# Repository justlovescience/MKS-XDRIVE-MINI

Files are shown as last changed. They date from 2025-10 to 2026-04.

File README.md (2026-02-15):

# MKS XDRIVE Mini FOC Driver: Full Setup Guide & Firmware

main

A comprehensive guide for the **MKS XDRIVE Mini**, a cost-effective, high-performance FOC driver for robotics. This repository contains configuration files, unbricking procedures, and multi-driver CAN bus setup instructions.

---

## 📺 Video Tutorial
Watch the step-by-step video guide here:
[**MKS XDRIVE Mini Full Instruction & Setup**](https://youtu.be/yRx7dsJmNvU?si=e_iXddEL_CQ9xSlw)

---

## 🚀 Quick Start (Windows)
Follow these steps to configure your driver using the ODrive tool:

1. **Install Python:** Download from python.org. 
   * **Important:** Select "Add python.exe to PATH" during installation.
2. **Install ODrive Tool:** Open PowerShell and install the ODrive package version 0.5.1.post0.
3. **Configuration:** Run **odrivetool** in your terminal. Use the commands provided in the **my_config.txt** file.
4. **Motor Tuning:** Ensure you set your pole pairs correctly. For example, for an LA8308 170kV motor, you would enter:
   **odrv0.axis0.motor.config.pole_pairs = 20**
   *Note: Calculate this by counting your motor magnets and dividing by 2.*

---

## 🛠 Hardware & Compatibility
* **Web GUI Interface:** For a visual setup, use this [Awesome WEB GUI](https://github.com/MoonLighTingPY/odrive3.6_web_gui).
* **Arduino/ESP32 Setup:** Ensure your board has CAN support.
    * For **ESP32**, place the **ODriveEsp32Twai.hpp** adapter in your arduino/libraries/OdriveArduino/src folder.
* **macOS Support:** odrivetool is functional on Mac, but the GUI is currently unsupported.

---

## ⚠️ Critical Notes & Troubleshooting

### 1. Avoid Bricking the Driver
* **Do NOT** use the "upgrade" command in odrivetool. This driver ships with modified **v0.5.1 firmware**; standard upgrades will brick the device.
* **Unbricking:** If bricked, you must use an **ST-Link programmer**. You can find dumped original firmware in this repository, you will need ST-linkV2 to unbrick.

### 2. CAN Bus Conflicts (Multi-Driver Setup)
By default, the MKS XDRIVE Mini acts like a dual-axis ODrive. This causes CAN ID conflicts when connecting multiple drivers.
* **The Fix:** Change the "ghost" Axis1 to a "listen-only" ID to clear the bus by setting:
  **odrv0.axis1.config.can_node_id = 63**

### 3. Firmware Versions
Current testing shows that updating to **v0.5.6** may result in motor inactivity (likely due to different pin assignments for the DRV8301). Stick to v0.5.1 for now. 

---

## 🔌 Wiring & Schematics
### ESP32-S3 Connection Diagram
esp32_s3_two_drivers_schematic

---
*Disclaimer: This repository is a community-made guide. I have no affiliation with the manufacturer.*

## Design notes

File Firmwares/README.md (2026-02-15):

here will be some firmwares for this driver, work in progress
MKS_XDRIVE_MINI_original_FW.bin is original firmware dumped from driver, in case you bricked yoor board with DFU update. You will need stlink to flash it.

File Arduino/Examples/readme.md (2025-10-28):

Couple examples of code to run drivers through CAN

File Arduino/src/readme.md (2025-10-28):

Put ODriveEsp32Twai.hpp in Odrive library folder

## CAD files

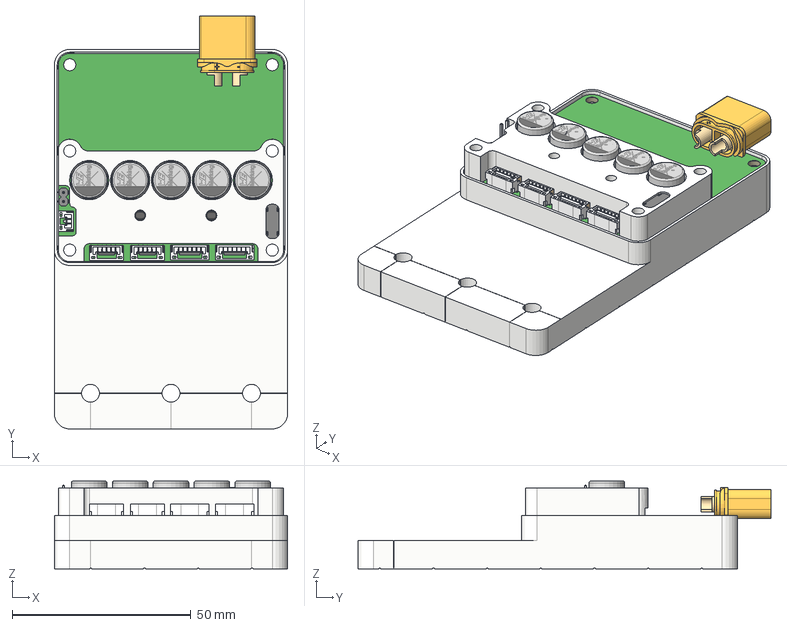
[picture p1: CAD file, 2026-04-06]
3Dmodels/LA8308 motor mount and driver assembly.step
65.2 x 115.4 x 24.6 mm

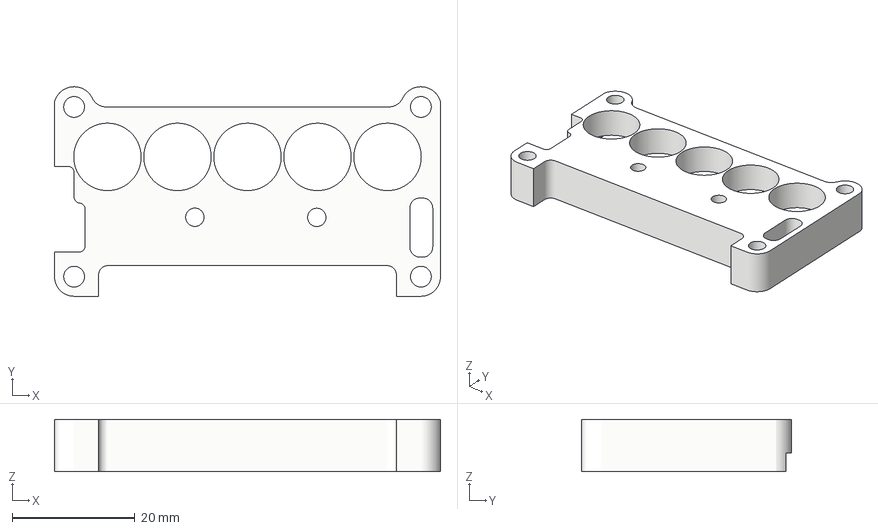
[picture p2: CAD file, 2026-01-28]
3Dmodels/half_bracket_for_3dprinting.3mf
63.0 x 34.2 x 8.50 mm

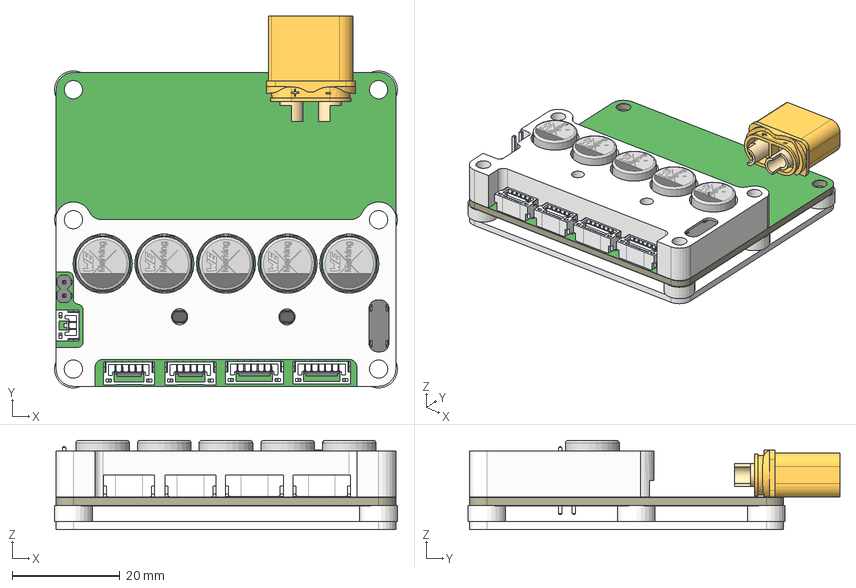
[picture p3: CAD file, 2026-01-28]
3Dmodels/mks xdrive mini xt60.step
63.6 x 68.9 x 16.6 mm

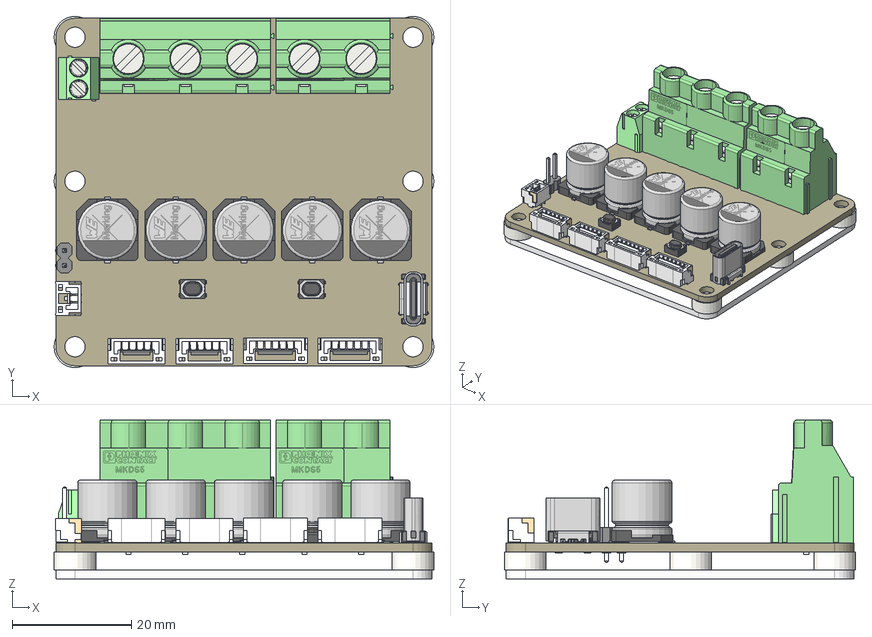
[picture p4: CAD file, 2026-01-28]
3Dmodels/mks xdrive mini.step
63.6 x 58.7 x 26.6 mm

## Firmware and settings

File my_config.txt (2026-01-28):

odrv0.erase_configuration() 						

odrv0.config.brake_resistance = 2.0
odrv0.config.dc_bus_undervoltage_trip_level = 8.0
odrv0.config.dc_bus_overvoltage_trip_level = 56.0
odrv0.config.dc_max_positive_current = 20.0
odrv0.config.dc_max_negative_current = -3.0
odrv0.config.max_regen_current = 0
odrv0.save_configuration()

odrv0.axis0.motor.config.pole_pairs = 20
odrv0.axis0.motor.config.calibration_current = 5
odrv0.axis0.motor.config.resistance_calib_max_voltage = 2
odrv0.axis0.motor.config.motor_type = MOTOR_TYPE_HIGH_CURRENT
odrv0.axis0.motor.config.current_lim = 15
odrv0.axis0.motor.config.requested_current_range = 20
odrv0.save_configuration()

odrv0.axis0.encoder.config.mode = ENCODER_MODE_SPI_ABS_AMS
odrv0.axis0.encoder.config.abs_spi_cs_gpio_pin = 7
odrv0.axis0.encoder.config.cpr = 16384
odrv0.axis0.encoder.config.bandwidth = 3000
odrv0.axis0.encoder.config.calib_range = 10
odrv0.save_configuration()

odrv0.axis0.controller.config.control_mode = CONTROL_MODE_POSITION_CONTROL
odrv0.axis0.controller.config.vel_limit = 120
odrv0.axis0.controller.config.pos_gain = 30
odrv0.axis0.controller.config.vel_gain = 0.02  				
odrv0.axis0.controller.config.vel_integrator_gain = 0.2
odrv0.axis0.controller.config.input_mode = INPUT_MODE_TRAP_TRAJ
odrv0.axis0.trap_traj.config.vel_limit = 30
odrv0.axis0.trap_traj.config.accel_limit = 5  
odrv0.axis0.trap_traj.config.decel_limit = 5
odrv0.save_configuration()
odrv0.reboot()

odrv0.axis0.requested_state = AXIS_STATE_MOTOR_CALIBRATION  		
odrv0.axis0.motor.config.pre_calibrated = True				
odrv0.axis0.requested_state = AXIS_STATE_ENCODER_OFFSET_CALIBRATION 	
odrv0.axis0.config.startup_encoder_offset_calibration = True   			
odrv0.axis0.requested_state = AXIS_STATE_CLOSED_LOOP_CONTROL		
odrv0.axis0.config.startup_closed_loop_control = True			
odrv0.save_configuration()
odrv0.reboot()  

odrv0.axis0.controller.input_pos = 50
odrv0.axis0.controller.input_pos = 0
odrv0.axis0.requested_state = AXIS_STATE_IDLE

odrv0.axis0.config.can_node_id = 0 
odrv0.can.set_baud_rate(500000)
odrv0.axis1.config.can_node_id = 63
  

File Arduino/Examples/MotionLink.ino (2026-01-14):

/*
 *  One way motion  control test
 * 
 * Test setup:
 * - Motor 0: Torque control mode with zero torque (move by hand)
 * - Motor 1: Position control mode following Motor 0's position
 * 
 * This tests the transition from torque control to position control.
 * 
 * Hardware:
 * - ESP32 + CAN transceiver
 * - Two ODrive motors (Node 0 and 1)
 */

#include <Arduino.h>
#include <ESP32-TWAI-CAN.hpp>
#include "ODriveCAN.h"
#include "ODriveEsp32Twai.hpp"

// Configuration
#define CAN_BAUDRATE   500000
#define TX_GPIO_NUM    5
#define RX_GPIO_NUM    4
#define ODRV0_NODE_ID  0
#define ODRV1_NODE_ID  1

// Position control parameters
#define POS_GAIN       20.0f   // Position gain for slave motor
#define VEL_GAIN       0.1f    // Velocity gain for slave motor
#define VEL_INT_GAIN   0.0f    // Velocity integrator gain
#define VEL_LIMIT      10.0f   // Velocity limit (rev/s)
#define CURRENT_LIMIT  10.0f   // Current limit (A)

// Update frequency parameters
#define UPDATE_FREQ_HZ  100    // Update frequency in Hz (100Hz = 10ms)
#define PRINT_FREQ_HZ  5       // Print frequency in Hz (5Hz = 200ms)

auto& can_intf = ESP32Can;

// ODrive instances
ODriveCAN odrv0(wrap_can_intf(can_intf), ODRV0_NODE_ID);
ODriveCAN odrv1(wrap_can_intf(can_intf), ODRV1_NODE_ID);

// Motor data
struct MotorData {
  float position_rad = 0.0f;
  float velocity_rad_s = 0.0f;
  bool has_feedback = false;
} master, slave;

// Callbacks
void onFB0(Get_Encoder_Estimates_msg_t& msg, void* user) {
  auto* d = static_cast<MotorData*>(user);
  d->position_rad = msg.Pos_Estimate * TWO_PI;
  d->velocity_rad_s = msg.Vel_Estimate * TWO_PI;
  d->has_feedback = true;
}

void onFB1(Get_Encoder_Estimates_msg_t& msg, void* user) {
  auto* d = static_cast<MotorData*>(user);
  d->position_rad = msg.Pos_Estimate * TWO_PI;
  d->velocity_rad_s = msg.Vel_Estimate * TWO_PI;
  d->has_feedback = true;
}

void onCanFrame(uint32_t id, uint8_t len, const uint8_t* data) {
  odrv0.onReceive(id, len, data);
  odrv1.onReceive(id, len, data);
}

// CAN setup
bool setupCan() {
  const auto kbps = CAN_BAUDRATE / 1000;
  can_intf.setPins(TX_GPIO_NUM, RX_GPIO_NUM);
  can_intf.setRxQueueSize(16);
  can_intf.setTxQueueSize(16);
  return can_intf.begin(can_intf.convertSpeed(kbps), TX_GPIO_NUM, RX_GPIO_NUM);
}

void setup() {
  Serial.begin(115200);
  while (!Serial && millis() < 4000) {}

  Serial.println("Torque to Position Control Test");
  Serial.println("===============================");
  Serial.println("Motor 0: Torque control (zero torque - move by hand)");
  Serial.println("Motor 1: Position control (follows Motor 0)");
  Serial.println();

  // Register callbacks
  odrv0.onFeedback(onFB0, &master);
  odrv1.onFeedback(onFB1, &slave);

  // Setup CAN
  if (!setupCan()) {
    Serial.println("CAN failed!");
    while (true) delay(100);
  }

  // Wait for ODrives to be ready
  Serial.println("Waiting for ODrives...");
  delay(2000);
  Serial.println("ODrives ready!");

  // Configure Motor 0 for torque control
  Serial.println("Configuring Motor 0 (Master) for torque control...");
  odrv0.setControllerMode(ODriveControlMode::CONTROL_MODE_TORQUE_CONTROL, ODriveInputMode::INPUT_MODE_PASSTHROUGH);
  odrv0.clearErrors();
  odrv0.setState(ODriveAxisState::AXIS_STATE_CLOSED_LOOP_CONTROL);

  // Configure Motor 1 for position control
  Serial.println("Configuring Motor 1 (Slave) for position control...");
  odrv1.setControllerMode(ODriveControlMode::CONTROL_MODE_POSITION_CONTROL, ODriveInputMode::INPUT_MODE_PASSTHROUGH);
  odrv1.setPosGain(POS_GAIN);
  odrv1.setVelGains(VEL_GAIN, VEL_INT_GAIN);
  odrv1.setLimits(VEL_LIMIT, CURRENT_LIMIT);
  odrv1.clearErrors();
  odrv1.setState(ODriveAxisState::AXIS_STATE_CLOSED_LOOP_CONTROL);

  // Wait for both motors to be in closed loop
  delay(3000);
  
  Serial.println("Configuration complete!");
  Serial.println("Motor 0: Torque control (move by hand)");
  Serial.println("Motor 1: Position control (will follow Motor 0)");
  Serial.println("Position Gain: " + String(POS_GAIN));
  Serial.println("Velocity Gain: " + String(VEL_GAIN));
  Serial.println("Velocity Limit: " + String(VEL_LIMIT) + " rev/s");
  Serial.println("Update Frequency: " + String(UPDATE_FREQ_HZ) + " Hz");
  Serial.println("Print Frequency: " + String(PRINT_FREQ_HZ) + " Hz");
  Serial.println();
}

void loop() {
  static uint32_t last_update = 0;
  static uint32_t last_print = 0;
  
  // Calculate update intervals
  uint32_t update_interval_ms = 1000 / UPDATE_FREQ_HZ;
  uint32_t print_interval_ms = 1000 / PRINT_FREQ_HZ;
  
  pumpEvents(can_intf);

  // Update control at specified frequency
  if (millis() - last_update >= update_interval_ms) {
    // Get feedback from both motors
    Get_Encoder_Estimates_msg_t fb;
    if (odrv0.getFeedback(fb, 10)) {
      master.position_rad = fb.Pos_Estimate * TWO_PI;
      master.velocity_rad_s = fb.Vel_Estimate * TWO_PI;
      master.has_feedback = true;
    }
    
    if (odrv1.getFeedback(fb, 10)) {
      slave.position_rad = fb.Pos_Estimate * TWO_PI;
      slave.velocity_rad_s = fb.Vel_Estimate * TWO_PI;
      slave.has_feedback = true;
    }

    // Motor 0: Apply zero torque (move by hand)
    odrv0.setTorque(0.0f);

    // Motor 1: Set position to follow Motor 0
    if (master.has_feedback && slave.has_feedback) {
      // Convert master position from radians to revolutions for ODrive
      float master_pos_rev = master.position_rad / TWO_PI;
      
      // Set slave motor position to match master
      odrv1.setPosition(master_pos_rev);
    }
    
    last_update = millis();
  }

  // Print status at specified frequency
  if (millis() - last_print >= print_interval_ms) {
    if (master.has_feedback && slave.has_feedback) {
      float pos_diff_rad = master.position_rad - slave.position_rad;
      float pos_diff_rev = pos_diff_rad / TWO_PI;
      
      Serial.print("Master: "); Serial.print(master.position_rad, 3);
      Serial.print("rad ("); Serial.print(master.position_rad / TWO_PI, 3);
      Serial.print("rev) | Slave: "); Serial.print(slave.position_rad, 3);
      Serial.print("rad ("); Serial.print(slave.position_rad / TWO_PI, 3);
      Serial.print("rev) | Diff: "); Serial.print(pos_diff_rad, 3);
      Serial.print("rad ("); Serial.print(pos_diff_rev, 3);
      Serial.print("rev) | Freq: "); Serial.print(UPDATE_FREQ_HZ);
      Serial.println("Hz");
    }
    last_print = millis();
  }

  // Small delay to prevent overwhelming the system
  delay(1);
}

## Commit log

2025-10-28 add schematics example
2026-01-14 Update and rename TorqueToPositionTest.ino to MotionLink.ino
2026-01-28 Update and rename my_config.json to my_config.txt
    [my_config.txt]
